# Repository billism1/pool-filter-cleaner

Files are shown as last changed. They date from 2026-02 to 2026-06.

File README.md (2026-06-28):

# Pool Filter Cleaner

A 3D-printable pool filter cleaning system designed to efficiently clean cylindrical pool filters by spraying them while they rotate. This system allows for thorough cleaning of pool filter cartridges without manual scrubbing.

**Attribution:** I designed and modeled all 3D parts for this horizontal stand myself in OpenSCAD, working from measurements I took of my own filters and equipment.

**Scope:** This is a horizontal rotisserie-style stand. The filter is carried at both ends on a single horizontal rod and spins freely on bearings while you spray it. It's an independent, personal, non-commercial project.

## Overview

This project provides a complete solution for cleaning cylindrical pool filters (typically 3 feet long × 9 inches diameter). The core system is a rotating support assembly (`filter_holder` + `leg_base` + `leg_foot`) that spins the filter during cleaning. The included nozzle model is optional and experimental.

### Key Features

- **Optional nozzle support** - Included nozzle is experimental; any strong, focused nozzle stream works
- **Rotating support system** - Allows filter to spin freely during cleaning
- **Modular aluminum rod construction** - Accommodates various filter lengths
- **Stable leg-base support design** - Provides secure support during operation
- **Standard garden hose compatibility** - 3/4" GHT threading

## Recommended Setup

This is the configuration I print and use, and the best starting point if you just want to build the stand. A complete list of every model and configuration, including all the alternative variants you can swap in, is listed and described in the sections further below: [Quick Reference](#quick-reference), [All Rendered STL Files](#all-rendered-stl-files), and [Components & Design Files](#components--design-files).

The recommended setup builds one **horizontal stand**: the filter and rod lie horizontally, supported at both ends, and the filter spins freely on bearings while you spray it.

> **Ready to print:** [`publication/pool-filter-cleaner.3mf`](publication/pool-filter-cleaner.3mf) contains all the pieces for this recommended setup, pre-arranged across multiple plates. Open it in your slicer to print them.

**Print this:**

| Qty | STL File | Purpose |
|-----|---|---|
| 4× | `leg_foot.stl` | One foot per leg (two legs on each of the two leg bases). |
| 2× | `filter_holder_interior-false_exterior-true.stl` | One pressed into each end of the cylindrical filter. |
| 1× | `leg_base_2_legs_both_sides-false.stl` | Supports one end of the horizontal aluminum rod (closed-end rod hole). |
| 1× | `leg_base_2_legs_top_insert.stl` | Supports the other end as an open-top cradle, so you can set the rod into it from above instead of pressing it into a tube end-first. |

**How it works:**
- Each **filter holder** presses into one end of the filter cartridge. An S6904ZZ bearing seats into the recessed pocket on the flange (outer) face of each holder. The pockets face *outward*, so each bearing presses up against the adjacent leg base. The single horizontal aluminum rod runs through both holders and the bearing inner races, and the rod is held fixed by the leg bases. As the filter is sprayed it spins, and the bearings carry that rotation against two stationary contacts at once: radially around the fixed rod, and axially against the fixed leg bases the bearing faces press into. Both contacts would otherwise drag, but the bearings cut the friction at each, so the filter keeps spinning freely.
- One end of the rod drops into the **top-insert cradle base**, the other end is captured by the **closed-end 2-leg base**. Using the cradle on one side lets you lay the loaded filter+rod assembly into the stand from above rather than sliding it in lengthwise.
- Each base splays into **two legs**; a **leg foot** caps each of the four leg rods for stable, non-marring contact with the ground.
- Everything is **press-fit**: bearings press into the holder pockets, and the rods press into the holder and base tubes. The set-screw holes in the tubes are optional; only add M4 screws if a joint feels too loose.

Hardware for this setup: 2× S6904ZZ bearings, 1× horizontal 3/4" rod, 4× leg rods, and optional M4 set screws. See [Additional Hardware Needed](#quick-reference) below for sizes.

The garden hose nozzle is optional; any sufficiently forceful nozzle stream works.

## Quick Reference

Pre-rendered STL files live in the [`STLs/`](STLs/) folder. They are generated from the SCAD source files with OpenSCAD (see [Generating STL Files](#generating-stl-files)).

| Component | SCAD File | STL File(s) in `STLs/` |
|---|---|---|
| **Filter Holder (Core Set, Standard)** | `filter_holder/filter_holder.scad` | `filter_holder_interior-false_exterior-true.stl` (default) |
| **Leg Base (2-leg, Core Set)** | `leg_base/leg_base_2_legs.scad` | `leg_base_2_legs_both_sides-true.stl` and `leg_base_2_legs_both_sides-false.stl` |
| **Leg Base (2-leg, Top-Insert Cradle)** | `leg_base/leg_base_2_legs_top_insert.scad` | `leg_base_2_legs_top_insert.stl` |
| **Leg Foot (Core Set)** | `leg_foot/leg_foot.scad` | `leg_foot.stl` |
| **Garden Hose Nozzle (Optional)** | `nozzle/nozzle/garden_hose_nozzle-5-prong-fan-out.scad` | `garden_hose_nozzle-5-prong-fan-out.stl` |

**Filter holder STL note:** `filter_holder.scad` exports four variants, one per combination of the `place_bearing_at_holder_interior` and `place_bearing_at_holder_exterior` flags:
- `filter_holder_interior-false_exterior-true.stl`: default (bearing seated on the exterior side)
- `filter_holder_interior-true_exterior-false.stl`
- `filter_holder_interior-true_exterior-true.stl`
- `filter_holder_interior-false_exterior-false.stl`

**Leg base STL note:** For `leg_base/leg_base_2_legs.scad`, the included exports cover both rod-hole styles:
- `*_both_sides-true.stl` (`horizontal_through_hole_both_sides = true`): rod hole goes through both sides
- `*_both_sides-false.stl` (`horizontal_through_hole_both_sides = false`): rod hole is closed on one end

**Nozzle STL note:** The garden hose nozzle is optional but is rendered like the other parts: `render_garden_hose_nozzle.ps1` (and `render_all.ps1`) export `garden_hose_nozzle-5-prong-fan-out.stl` (see [Generating STL Files](#generating-stl-files)).

**Core solution note:** `filter_holder` + `leg_base` + `leg_foot` are an atomic set and are intended to be used together. The nozzle is optional/experimental; any effective high-force nozzle stream can be used.

**Additional Hardware Needed:**
- 2× S6904ZZ ball bearings (37mm × 20mm × 9mm)
- 1× Horizontal 3/4" aluminum rod (36-40" length)
- 4× Leg support 3/4" aluminum rods (24-36" length each)
- Optional: up to 6× M4 set screws (holes are already included in the models if you want to use them)

## All Rendered STL Files

Every part is committed pre-rendered in [`STLs/`](STLs/). The [Recommended Setup](#recommended-setup) above is the specific combination I settled on and use; every other STL listed here is an available alternative, included so you can experiment with a different bearing placement, rod-hole style, or stand configuration if you want to try something else. All permutations are provided so you can pick whichever fits your build:

| STL File | Source SCAD | Parameters baked in |
|---|---|---|
| `filter_holder_interior-false_exterior-true.stl` | `filter_holder/filter_holder.scad` | bearing in flange (exterior), **default** |
| `filter_holder_interior-true_exterior-false.stl` | `filter_holder/filter_holder.scad` | bearing at plug end (interior) |
| `filter_holder_interior-true_exterior-true.stl` | `filter_holder/filter_holder.scad` | bearing pockets at both ends |
| `filter_holder_interior-false_exterior-false.stl` | `filter_holder/filter_holder.scad` | no bearing pocket |
| `leg_base_2_legs_both_sides-true.stl` | `leg_base/leg_base_2_legs.scad` | rod hole through both sides |
| `leg_base_2_legs_both_sides-false.stl` | `leg_base/leg_base_2_legs.scad` | rod hole closed on one end |
| `leg_base_2_legs_top_insert.stl` | `leg_base/leg_base_2_legs_top_insert.scad` | open-top cradle (rod laid in from above) |
| `leg_foot.stl` | `leg_foot/leg_foot.scad` | single variant |
| `garden_hose_nozzle-5-prong-fan-out.stl` | `nozzle/nozzle/garden_hose_nozzle-5-prong-fan-out.scad` | single variant, optional/experimental |

The garden hose nozzle is optional, but it is rendered alongside the other parts (`render_garden_hose_nozzle.ps1`, also covered by `render_all.ps1`). You can swap in any nozzle with an adequately forceful stream instead.

## Components & Design Files

### 1. Filter Holder

**File:** `filter_holder/filter_holder.scad`  
**STL Outputs:** four bearing-placement variants in `STLs/` (see table above); `filter_holder_interior-false_exterior-true.stl` is the default.

**Variant note:** The four STLs are the permutations of `place_bearing_at_holder_interior` and `place_bearing_at_holder_exterior`. Use the default (`interior-false_exterior-true`) unless you have a reason to seat the bearing differently.

The filter holder attaches to the pool filter cartridge and provides the mounting point for the support rod. This component includes an integrated bearing holder for smooth rotation.

**Key Features:**
- Tapered plug (76.2mm diameter) that fits snugly into the 3" filter opening
- Large flange (140mm diameter) that sits outside the filter
- Six 1-inch (25.4mm) drainage holes evenly spaced around the flange
- Bearing holder tube extension for S6904ZZ bearing (37mm OD × 20mm ID × 9mm thick)
- 4mm thick walls around bearing holder
- Ring cutout inside bearing area for clearance (starts 0.633mm from rod hole, 2.5mm thick, 2mm deep)
- 3mm diameter screw hole through bearing holder walls for securing bearing
- Central 19.05mm (3/4") hole for aluminum support rod
- All dimensions in millimeters

**Bearing Specifications:**
- S6904ZZ Ball Bearing: Stainless steel, double shielded, deep groove
- Dimensions: 37mm OD × 20mm ID × 9mm thick
- Allows filter to spin freely on the stationary aluminum rod

**Important:** Print TWO of these holders - one for each end of the filter.

### 2. Leg Base / Support Stand

**Primary file:** `leg_base/leg_base_2_legs.scad`  
**Top-insert variant:** `leg_base/leg_base_2_legs_top_insert.scad` (open-top cradle; rod is laid in from above instead of inserted end-first)  
**STL Outputs:** `STLs/leg_base_2_legs_both_sides-true.stl`, `STLs/leg_base_2_legs_both_sides-false.stl`, `STLs/leg_base_2_legs_top_insert.stl`

A leg-base connector that forms the base of the rotating support system, with two legs splaying from the horizontal rod tube.

**Specifications:**
- Designed for 3/4" (19.05mm) aluminum rods
- Horizontal tube (40mm length) for main filter rod
- Two leg tubes (47.85mm length each) angled at 45° downward
- Legs positioned 90° apart from each other
- 12° inward tilt on legs for bearing pressure toward filter
- 6mm wall thickness for structural strength
- Integrated bearing lip (2mm thick, 2mm extension) with curved flare
- Curved printing base for stable bed adhesion
- Set screw holes (4mm diameter) in all three tubes for rod retention
- Rod holes extend 35mm deep into leg tubes
- Requires BOSL2 library for advanced geometry operations

**Export variants:**
- `*_both_sides-true.stl` is rendered with `horizontal_through_hole_both_sides = true`
- `*_both_sides-false.stl` is rendered with `horizontal_through_hole_both_sides = false`

**Top-insert cradle variant:**
- `leg_base/leg_base_2_legs_top_insert.scad` is an open-top cradle: the horizontal rod is laid in from above (+Y) rather than pressed into a closed tube end-first, which can make assembly easier.

**Dependencies:**
- BOSL2 library (https://github.com/BelfrySCAD/BOSL2) - Advanced geometry and rounding functions

**Test/Development Files:**
- `leg_base/testing/base_test.scad` - Test variations of base geometry
- `leg_base/testing/curved_base.scad` - Development file for curved base design

**Important:** Print TWO of these bases - one for each end of the horizontal filter rod.

### 3. Leg Foot

**File:** `leg_foot/leg_foot.scad`  
**STL Output:** `STLs/leg_foot.stl`

Leg feet pair with the leg-base tubes and are part of the core support set.

**Important:** Print TWO leg feet and use them with the matching holder/base set.

### 4. Garden Hose Nozzle (Optional / Experimental)

#### Main Design File
**File:** `nozzle/nozzle/garden_hose_nozzle-5-prong-fan-out.scad`  
**STL Output:** `STLs/garden_hose_nozzle-5-prong-fan-out.stl` (rendered by `render_garden_hose_nozzle.ps1`)

This nozzle design is optional and experimental. You can use any nozzle that provides an adequately forceful stream for cleaning.

**Recommended print/process for watertightness:**
- Print the nozzle in ABS or ASA (recommended)
- Acetone vapor smooth both the inside and outside surfaces after printing
- This helps eliminate layer-line seepage; in ASA testing, small water beads/leaks through print lines stopped after vapor smoothing

**Specifications:**
- 3/4" female garden hose threading (GHT)
- 5 outlet nozzles with 1.72mm diameter openings
- Total outlet area: 11.69 mm²
- Hex grip ring for easy tightening (toggleable)
- Smooth hydrodynamic internal transitions for optimal water distribution
- Multi-stage hull transitions from cylinder to individual cone nozzles

**Dependencies:**
- `nozzle/nozzle/Threading.scad` - Library for generating 3/4" GHT female threads
- `nozzle/nozzle/Naca_sweep.scad` - Sweep and extrusion library for complex geometry

### Library Files

#### Threading.scad
**File:** `nozzle/nozzle/Threading.scad`

Comprehensive threading library by Rudolf Huttary (Berlin, 2016-2021) for generating various thread types in OpenSCAD.

**Capabilities:**
- Standard metric threads (ISO)
- ACME threads
- Multiple helix threads
- Left-hand and right-hand threads
- Customizable pitch, diameter, windings, and thread angle
- Used for generating 3/4" GHT (Garden Hose Thread) in nozzle designs

**Key Functions:**
- `threading()` - Creates a threaded rod or bolt
- `Threading()` - Creates a threaded nut or female thread

#### Naca_sweep.scad
**File:** `nozzle/nozzle/Naca_sweep.scad`

Sweep and extrusion library by Rudolf Huttary (2015-2020) for creating complex 3D shapes from 2D profiles.

**Capabilities:**
- Sweep 2D profiles along 3D paths
- Create smooth transitions between different cross-sections
- Skin multiple polygons together
- Matrix/vector transformations (translation, rotation, scaling)
- Path subdivision for smooth curves

**Key Functions:**
- `sweep()` - Main sweep/extrusion function
- `sweep_path()` - Sweep a shape along a path
- Affine transformations: `T()`, `R()`, `S()` for translate, rotate, scale

## Assembly Overview

The complete cleaning system consists of:

### Hardware Requirements
1. **Two 3D-printed filter holders** (`filter_holder/filter_holder.scad`)
   - Install one on each end of the filter cartridge
   
2. **Two 3D-printed leg bases** (`leg_base/leg_base_2_legs.scad`)
   - Position one at each end of the horizontal support rod

3. **Two 3D-printed leg feet** (`leg_foot/leg_foot.scad`)
   - Install on the ends of the inserted leg rods
   
4. **Optional 3D-printed garden hose nozzle** (`nozzle/nozzle/garden_hose_nozzle-5-prong-fan-out.scad`)
   - Optional experimental nozzle; any nozzle with an adequately forceful stream works
   
5. **Two S6904ZZ stainless steel ball bearings**
   - 37mm OD × 20mm ID × 9mm thick
   - One for each filter holder
   
6. **One horizontal 3/4" (19.05mm) aluminum rod**
   - Length varies based on filter size (typically 36-40" for standard filters)
   - Passes through bearing holders and leg bases
   
7. **Four 3/4" (19.05mm) aluminum rod legs**
   - Two legs per base (four total for both ends)
   - Length depends on desired working height (typically 24-36")
   
8. **Optional set screws** (M4 or #8-32)
   - Holes are already included in the printed models if you want to secure rods in filter holders and leg bases
   - Up to six screws total (one per tube connection)

### Assembly Steps

1. **Prepare filter holders:**
   - Press S6904ZZ bearings into the bearing holder tubes on each filter holder
   - Secure bearings with 3mm screws through side holes
   
2. **Mount filter holders to filter:**
   - Insert tapered plugs into both ends of the pool filter cartridge
   - The flanges should sit flat against the filter ends
   - Water drainage occurs through the six holes in each flange
   
3. **Install horizontal rod:**
   - Slide the horizontal 3/4" aluminum rod through both filter holders
   - The rod passes through the bearings, allowing the filter to rotate freely
   - Adjust rod position to center the filter
   
4. **Attach leg bases:**
   - Slide one leg base onto each end of the horizontal rod
   - Position them outside the filter holders
   - Optional: tighten set screws in the horizontal tubes to secure bases
   
5. **Install support legs:**
   - Insert two 3/4" aluminum rods into the angled leg sockets on each base
   - Adjust leg extension for desired working height
   - Optional: tighten set screws to secure legs
   
6. **Connect nozzle (optional):**
   - Attach the included 5-prong nozzle or any suitable high-force nozzle to your garden hose
   - Hand-tighten using the hex grip ring (if using the included model)
   
7. **Operation:**
   - Position the assembly on level ground
   - Turn on water supply
   - Manually rotate the filter or let water pressure cause rotation
   - The five concentrated jets clean the filter pleats thoroughly

The bearings allow the filter to spin freely on the stationary aluminum rod while water jets from the nozzle clean the exterior.

## 3D Printing Instructions

### General Settings
- **Material:** PETG or ABS recommended for outdoor durability and chemical resistance
  - PETG: Easier to print, good UV resistance, excellent layer adhesion
  - ABS: Higher temperature resistance, more rigid, requires heated enclosure
- **Infill:** 30-40% for structural components (leg bases, filter holders), 20-30% for nozzle
- **Layer Height:** 0.2mm standard, 0.15mm for higher detail
- **Print Speed:** 40-60mm/s for best quality
- **Supports:** Minimal - most designs optimized for support-free printing

### Component-Specific Notes

#### Filter Holder
- **Orientation:** Print with flange side down (largest flat surface on build plate)
- **Supports:** None required - bearing holder and drain holes designed to print without supports
- **Post-Processing:** Clean any stringing from drain holes and bearing holder

#### Leg Base
- **Orientation:** Print with curved base on build plate (already optimized for this orientation)
- **Supports:** None required - design includes integrated printing base that gets cut off
- **Post-Processing:** May need to drill set screw holes to final size depending on printer precision

#### Garden Hose Nozzle
- **Orientation:** Print with threaded end down (flat surface on build plate)
- **Supports:** Minimal supports may be needed for underside of hex grip ring
- **Thread Quality:** Ensure $fn is set to 180 or higher for smooth threads
- **Material Recommendation:** ABS or ASA for best water sealing performance
- **Post-Processing:** Use acetone vapor smoothing on both inside and outside surfaces to reduce/close layer-line seepage, then test thread fit with garden hose

### Quality Tips
1. **First Layer:** Critical for all parts - ensure proper bed leveling and adhesion
2. **Thread Testing:** Print a small thread test piece before committing to full nozzle print
3. **Bearing Fit:** Filter holder bearing pocket should be snug - may need light sanding for perfect fit
4. **Rod Holes:** Should allow smooth sliding of 3/4" aluminum rod - sand lightly if too tight
5. **Layer Adhesion:** Important for water-tight performance of nozzle - avoid drafts and temperature fluctuations

## Usage & Operation

### Setup
1. **Assemble the base structure** with aluminum rods and 3D-printed leg bases
2. **Install bearings** into filter holders and secure with set screws
3. **Mount filter holders** on both ends of the pool filter cartridge
4. **Slide horizontal rod** through filter holders and bearings
5. **Attach leg bases** to rod ends (optional set screws can be used via the built-in holes)
6. **Insert support legs** into angled sockets (optional set screws can be used via the built-in holes)
7. **Level the assembly** on flat ground, adjust leg heights if needed

### Cleaning Operation
1. **Connect nozzle** (included optional model or any suitable high-force nozzle) to garden hose with good water pressure (30-50 PSI recommended)
2. **Position nozzle** 6-12 inches from filter surface
3. **Turn on water** - the five jets will spray concentrated streams across the filter
4. **Rotate the filter** manually or allow water pressure to spin it on the bearings
5. **Move nozzle** along the length of the filter for complete coverage
6. **Continue until clean** - typically 2-5 minutes per filter depending on debris level

### Maintenance
- **After each use:** Rinse nozzle to prevent buildup
- **Weekly (if using set screws):** Check set screws and tighten if needed
- **Monthly:** Inspect bearings for smooth rotation, clean if necessary
- **Annually:** Check 3D-printed parts for wear or UV damage

### Safety Notes
- Always use on level ground to prevent tipping
- If using set screws, ensure they are tight before adding water pressure
- Do not exceed 80 PSI water pressure to avoid damaging components
- Keep electrical equipment away from water spray area

## Design Software & Dependencies

### OpenSCAD
All components are designed in **OpenSCAD** (parametric 3D CAD modeler), allowing for easy customization and adjustments for different filter sizes or rod diameters.

**Download:** https://openscad.org/

**Recommended Version:** OpenSCAD 2021.01 or newer

### Required Libraries

#### BOSL2 (for leg base SCAD files)
**Repository:** https://github.com/BelfrySCAD/BOSL2  
**Purpose:** Advanced geometric operations, rounding, and shape manipulation  
**Installation:** 
1. Download or clone the BOSL2 repository
2. Place in OpenSCAD's library path or in the project directory
3. The leg base files use `include <BOSL2/std.scad>`

#### Threading.scad (included)
**Location:** `nozzle/nozzle/Threading.scad`  
**Purpose:** Generate GHT and other thread types  
**Author:** Rudolf Huttary, Berlin (2016-2021)  
**Note:** Already included in project, no separate installation needed

#### Naca_sweep.scad (included)
**Location:** `nozzle/nozzle/Naca_sweep.scad`  
**Purpose:** Sweep and extrusion operations for complex geometry  
**Author:** Rudolf Huttary, Berlin (2015-2020)  
**Note:** Already included in project, no separate installation needed

### Rendering Settings

For quick previews during development:
```openscad
$fn = 60;  // Lower resolution, faster rendering
```

For final STL export:
```openscad
$fn = 180;  // Higher resolution, smoother curves
```

Each file has its `$fn` parameter clearly marked at the top for easy adjustment.

## Generating STL Files

Pre-rendered STLs are committed in [`STLs/`](STLs/), so you only need to regenerate them if you change a SCAD file or want a different parameter variant. All generation goes through OpenSCAD; the PowerShell scripts are just a convenience wrapper around it.

**Prerequisites:**
- [OpenSCAD](https://openscad.org/) installed (2021.01 or newer; a recent Nightly build is recommended because it ships the more robust `manifold` geometry backend).
- The [BOSL2](https://github.com/BelfrySCAD/BOSL2) library on OpenSCAD's library path, required by all `leg_base` SCAD files. The nozzle's `Threading.scad` and `Naca_sweep.scad` are already bundled in the repo.

### Option A: PowerShell scripts (Windows)

The repo includes `render_*.ps1` scripts that drive OpenSCAD for you. Each part has its own script, and `render_all.ps1` runs every one of them. They write into the `STLs/` folder and automatically:
- locate OpenSCAD (preferring `C:\Program Files\OpenSCAD (Nightly)\openscad.exe`, then the stable install, then `openscad` on `PATH`),
- enable `--backend=manifold` when the installed build supports it,
- render every parameter permutation for the multi-variant parts.

```powershell
# Render everything into STLs\
powershell -ExecutionPolicy Bypass -File render_all.ps1

# Or render a single part
powershell -ExecutionPolicy Bypass -File render_filter_holder.ps1
powershell -ExecutionPolicy Bypass -File render_leg_base_2_legs.ps1
powershell -ExecutionPolicy Bypass -File render_leg_base_2_legs_top_insert.ps1
powershell -ExecutionPolicy Bypass -File render_leg_foot.ps1
powershell -ExecutionPolicy Bypass -File render_garden_hose_nozzle.ps1
```

| Script | Renders |
|---|---|
| `render_all.ps1` | Every part script below |
| `render_filter_holder.ps1` | 4 filter-holder bearing-placement variants |
| `render_leg_base_2_legs.ps1` | 2-leg base, both `horizontal_through_hole_both_sides` values |
| `render_leg_base_2_legs_top_insert.ps1` | Top-insert cradle base (single variant) |
| `render_leg_foot.ps1` | Leg foot (single variant) |
| `render_garden_hose_nozzle.ps1` | Garden hose nozzle (single variant, optional) |

`render_common.ps1` holds the shared OpenSCAD-locating and rendering helpers; it is dot-sourced by the others and is not run directly.

### Option B: OpenSCAD directly

Open any `.scad` file in the OpenSCAD GUI and use **File → Export → Export as STL** (after a full render with F6), or render from the command line. The command line is what the PowerShell scripts call under the hood, so you can reproduce any committed STL exactly.

```bash
# Single-variant parts
openscad --backend=manifold -o STLs/leg_foot.stl leg_foot/leg_foot.scad
openscad --backend=manifold -o STLs/leg_base_2_legs_top_insert.stl leg_base/leg_base_2_legs_top_insert.scad

# Parameterized variants: override values with -D
openscad --backend=manifold \
  -D place_bearing_at_holder_interior=false \
  -D place_bearing_at_holder_exterior=true \
  -o STLs/filter_holder_interior-false_exterior-true.stl \
  filter_holder/filter_holder.scad

openscad --backend=manifold \
  -D horizontal_through_hole_both_sides=true \
  -o STLs/leg_base_2_legs_both_sides-true.stl \
  leg_base/leg_base_2_legs.scad

# Optional nozzle (also produced by render_garden_hose_nozzle.ps1)
openscad --backend=manifold \
  -o STLs/garden_hose_nozzle-5-prong-fan-out.stl \
  nozzle/nozzle/garden_hose_nozzle-5-prong-fan-out.scad
```

Notes:
- Drop `--backend=manifold` on older OpenSCAD builds that don't support it.
- Each SCAD file's `$fn` defaults to 180 for smooth final exports; lower it to ~60 for faster preview renders (the nozzle threads in particular want `$fn` 180+).

## Project Status

### Completed Components ✅
- **Garden hose nozzle** - Optional experimental add-on
  - 5-prong fan-out configuration optimized for filter cleaning
  - GHT threading with hex grip for easy installation
   - Any adequately forceful nozzle stream can be used instead
  
- **Filter holder** - Complete design with bearing integration
  - Tapered plug fits standard 3" pool filter openings
  - Integrated S6904ZZ bearing holder with retention screw
  - Drainage holes for water flow
  - Ring cutout for proper bearing clearance
  
- **Leg base / Support stand** - Fully designed and ready for printing
   - 2-leg connector with top-insert cradle variant available
  - Curved printing base for stability
  - Bearing lip for smooth rotation interface
  - Set screw holes for secure rod retention

### Documentation 📋
- ✅ Component specifications documented
- ✅ File organization and purposes documented
- ✅ Assembly instructions provided
- ✅ Hardware requirements listed
- ✅ Printing parameters specified
- 🚧 Photos/renders of assembled system - Pending
- 🚧 Video demonstration - Pending

### Future Enhancements 💡
- Extended reach nozzle variants for larger filters
- Motorized rotation option
- Alternative bearing holder designs for different bearing sizes
- Adjustable height leg bases
- Integrated tool holder for maintenance accessories

## License

This project is licensed under the MIT License. See [LICENSE](LICENSE) for details.

Feel free to modify and improve the designs for your own use.

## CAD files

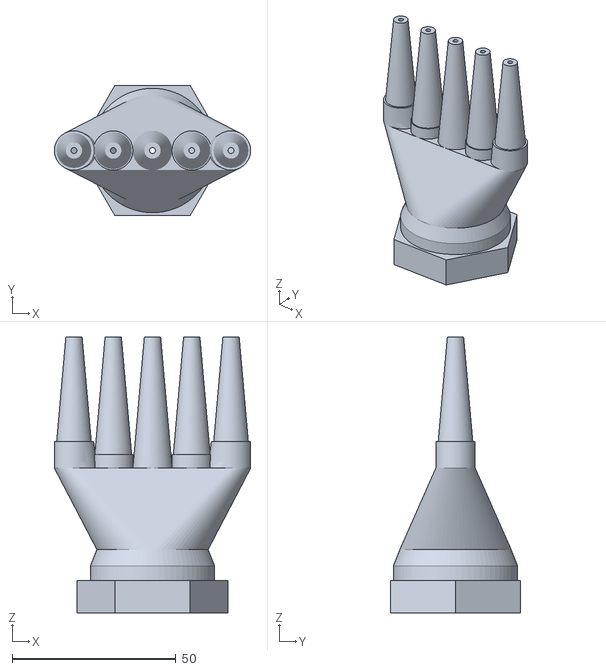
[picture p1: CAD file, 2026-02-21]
nozzle/testing/nozzle2/STLs/garden_hose_nozzle-5-prong-fan-out-2 - rev2.stl
60.0 x 39.8 x 84.4

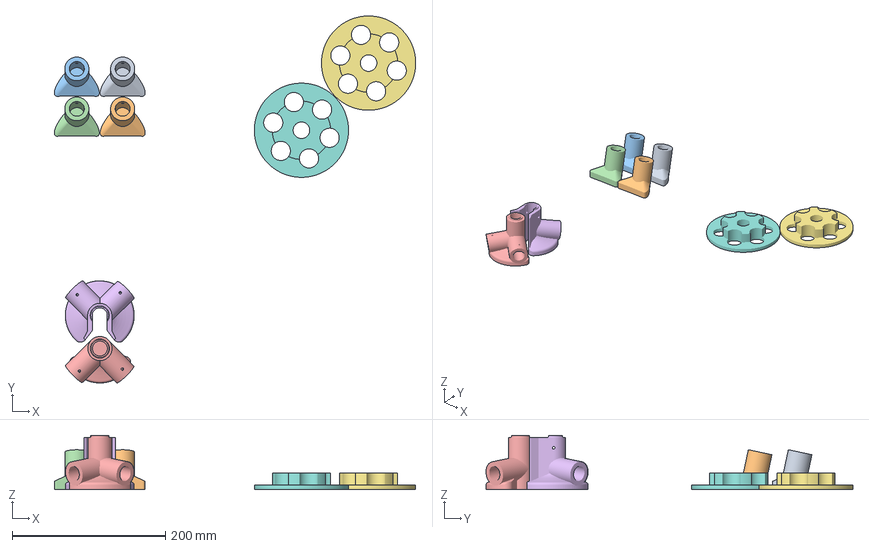
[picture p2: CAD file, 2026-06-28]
publication/pool-filter-cleaner.3mf
471.8 x 479.2 x 71.0 mm
leg_foot.stl x 4
leg_base_2_legs_both_sides-false.stl
leg_base_2_legs_top_insert.stl
filter_holder_interior-false_exterior-true.stl x 2

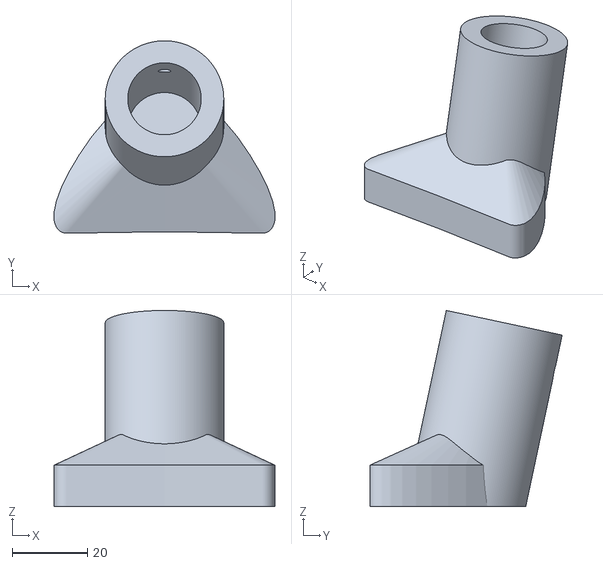
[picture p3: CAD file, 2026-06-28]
STLs/leg_foot.stl
58.8 x 51.2 x 52.2

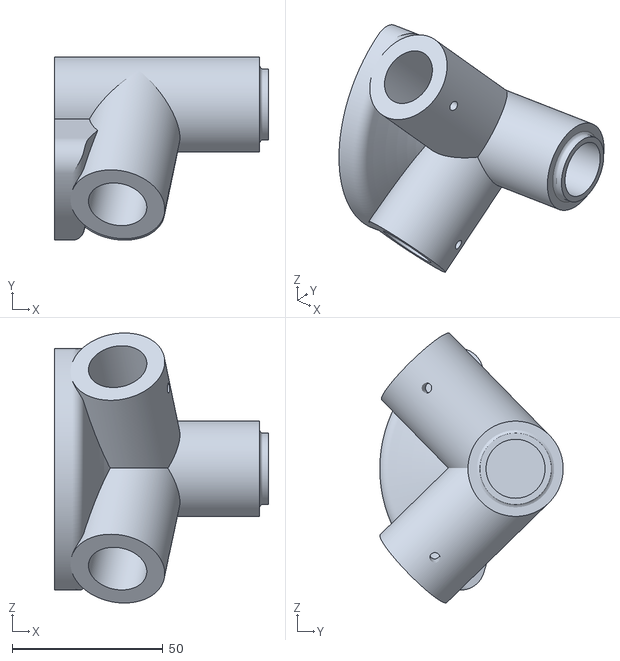
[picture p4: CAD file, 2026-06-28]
STLs/leg_base_2_legs_both_sides-false.stl
71.0 x 60.8 x 89.5

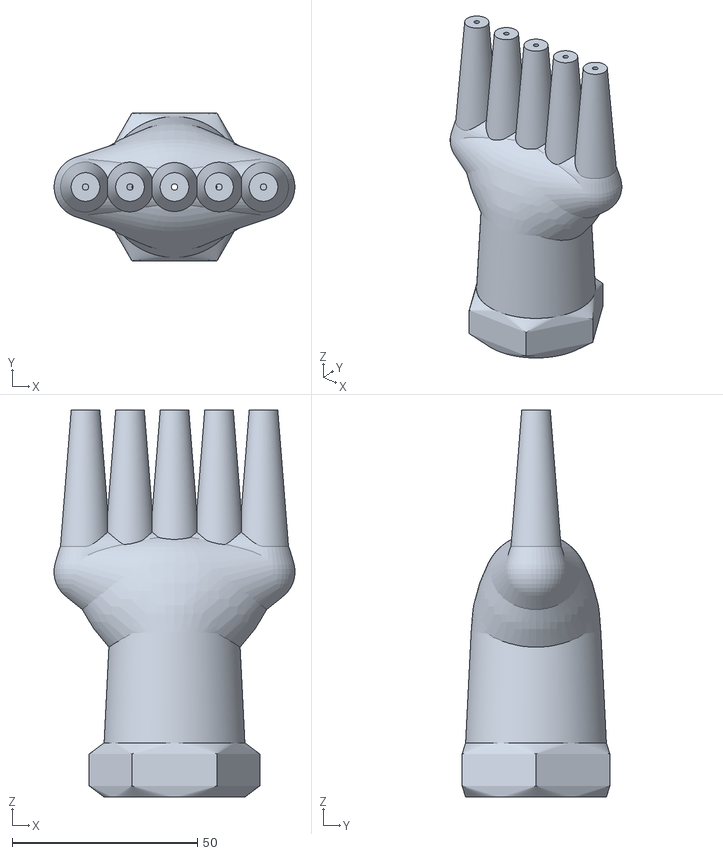
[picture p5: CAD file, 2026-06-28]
STLs/garden_hose_nozzle-5-prong-fan-out.stl
64.9 x 39.8 x 104.4

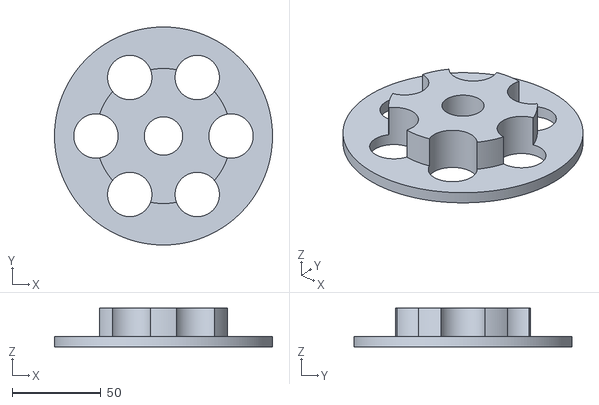
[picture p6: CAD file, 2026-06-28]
STLs/filter_holder_interior-false_exterior-true.stl
123.0 x 123.0 x 22.0

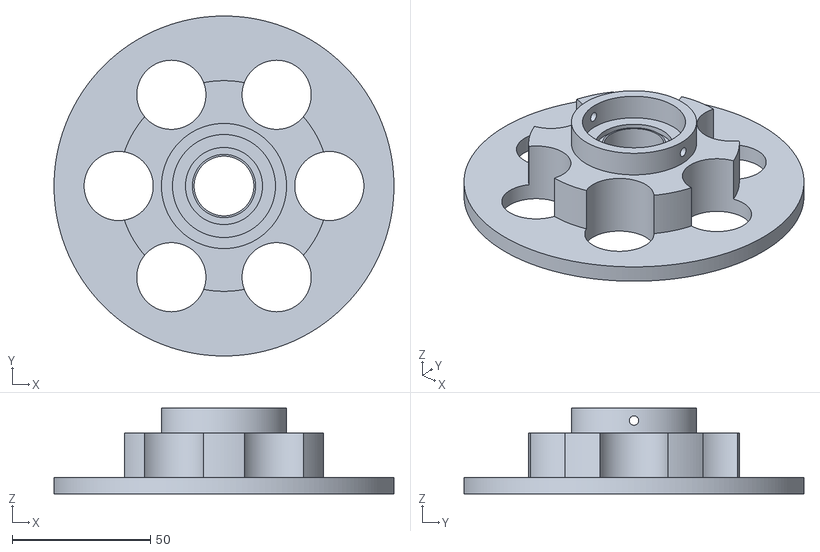
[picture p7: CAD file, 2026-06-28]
STLs/filter_holder_interior-true_exterior-false.stl
123.0 x 123.0 x 31.0

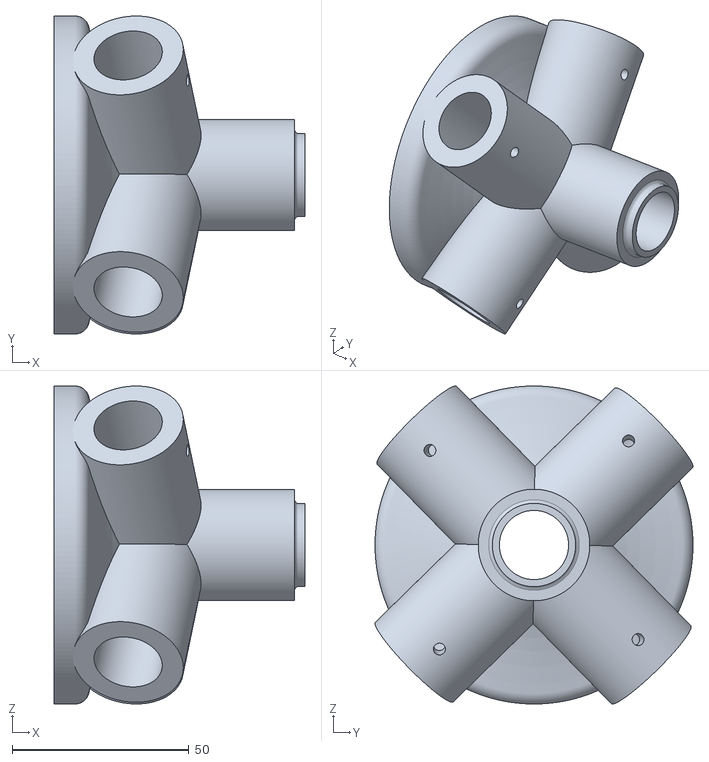
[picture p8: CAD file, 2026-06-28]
STLs/leg_base_4_legs_both_sides-true.stl
71.0 x 90.0 x 90.0

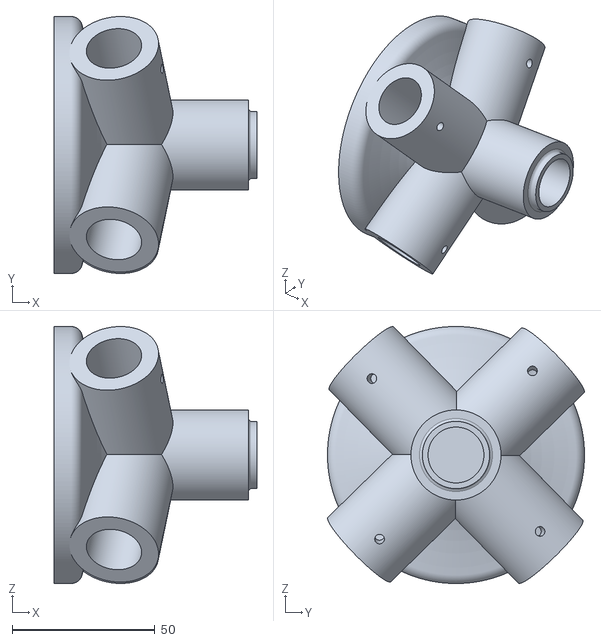
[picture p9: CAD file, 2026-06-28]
STLs/leg_base_4_legs_both_sides-false.stl
71.0 x 90.0 x 90.0

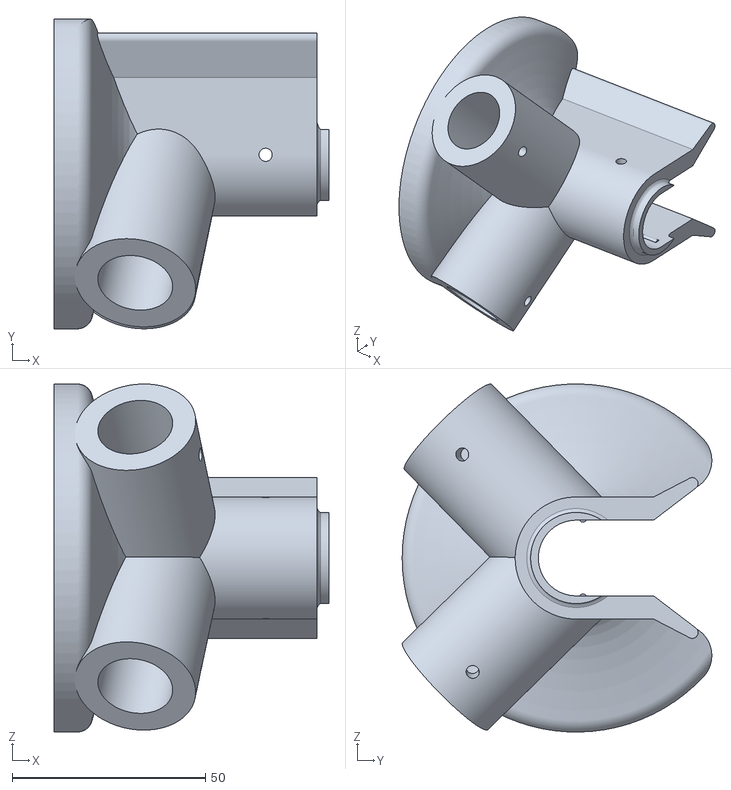
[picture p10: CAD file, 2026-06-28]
STLs/leg_base_2_legs_top_insert.stl
71.0 x 80.1 x 90.0

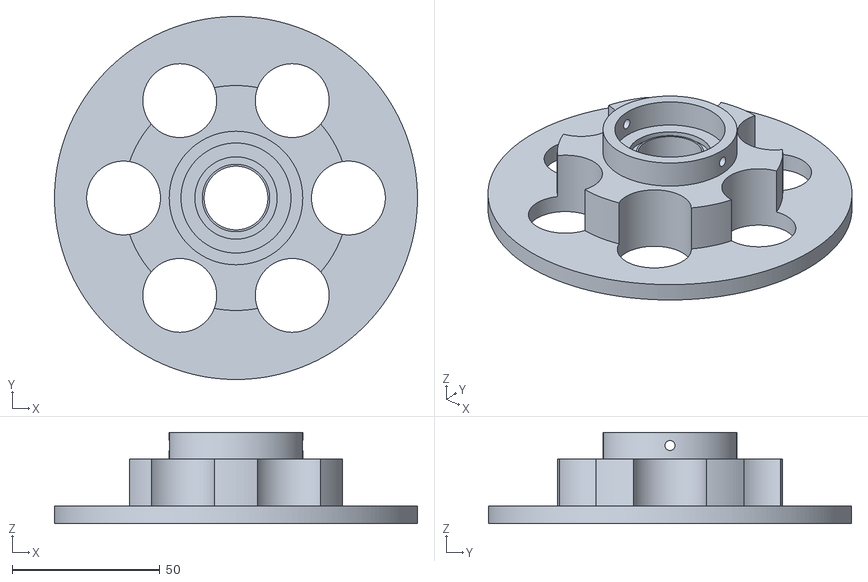
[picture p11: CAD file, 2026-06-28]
STLs/filter_holder_interior-true_exterior-true.stl
123.0 x 123.0 x 31.0

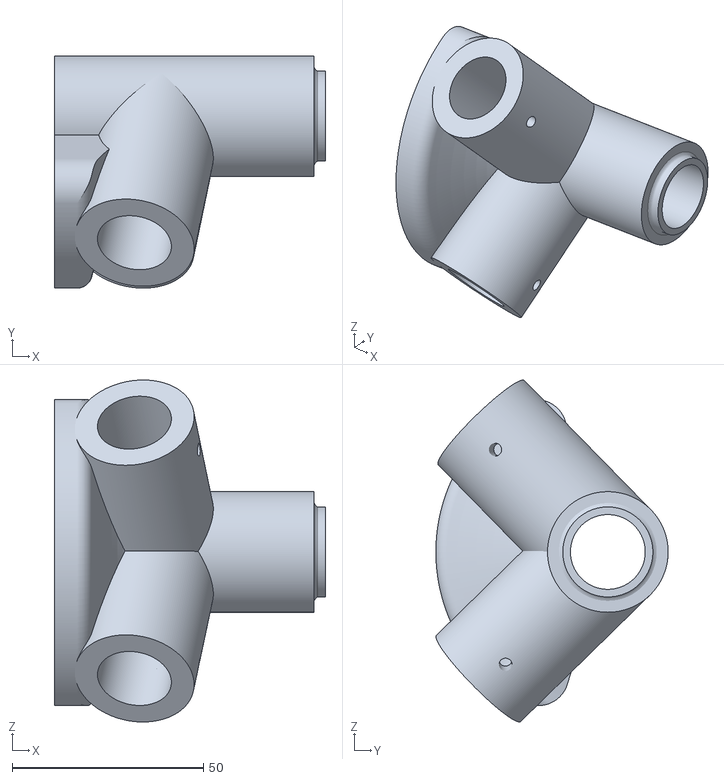
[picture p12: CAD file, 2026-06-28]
STLs/leg_base_2_legs_both_sides-true.stl
71.0 x 60.8 x 89.5

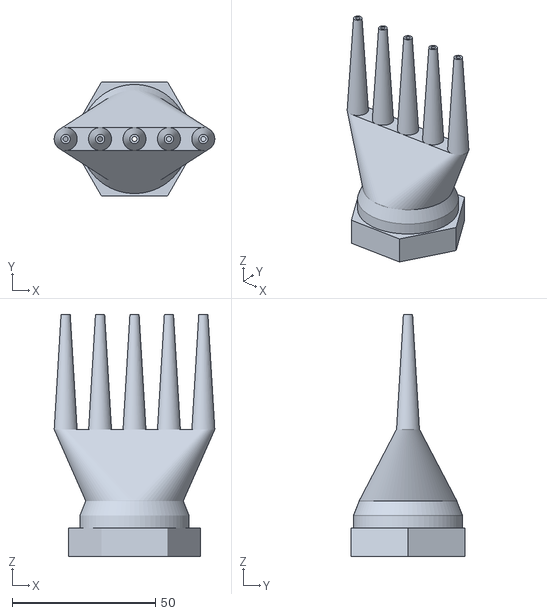
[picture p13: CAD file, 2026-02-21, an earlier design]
nozzle/testing/nozzle2/STLs/garden_hose_nozzle-5-prong-fan-out-2 - rev1.stl
56.0 x 39.8 x 84.4

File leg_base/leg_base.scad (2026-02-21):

// Pool Filter Cleaner - Base Holder
// Holds 3/4" aluminum rod horizontally (for filter cylinder)
// Plus two 3/4" aluminum rod legs angled down at 45 degrees, 90 degrees apart
// Creates a stable tripod support structure (use 2 of these bases, one at each end)

include <BOSL2/std.scad>
// https://github.com/BelfrySCAD/BOSL2

$fn = 180;  // Reduce to 60 for faster preview, increase to 180+ to for final render

// Rod specifications
rod_diameter = 19.05;        // 3/4" aluminum rod = 19.05mm
rod_clearance = 0.5;         // Clearance for easy insertion
rod_hole_diameter = rod_diameter + rod_clearance;

// Tube dimensions
tube_wall_thickness = 6;     // Thick walls for strength
tube_inner_diameter = rod_hole_diameter;
tube_outer_diameter = tube_inner_diameter + (tube_wall_thickness * 2);

// Length dimensions
horizontal_tube_length = 40;  // Length of horizontal tube section
leg_tube_length = 47.85;         // Length of each leg tube section
leg_hole_depth = 35;          // How deep leg holes go (stops well before center)

// Leg angle
leg_angle = 45;  // Degrees down from horizontal
inward_tilt_angle = 12;  // Slight inward tilt toward filter for bearing pressure

// Bearing lip dimensions
bearing_lip_extension = 2;   // How far the lip extends inward (mm)
bearing_lip_thickness = 2;   // Thickness of the bearing lip wall (mm)
bearing_lip_od = tube_inner_diameter + (bearing_lip_thickness * 2);  // Outer diameter matches tube inner diameter
bearing_lip_id = bearing_lip_od - (bearing_lip_thickness * 2);  // Inner diameter for rod clearance
bearing_lip_flare_length = 1; // Length of the curved flare section
bearing_lip_flare_amount = 1; // How much it flares outward (mm added to radius)

// Horizontal hole configuration
horizontal_through_hole_both_sides = true;  // If true, rod hole goes through both sides; if false, only extends in positive X direction

// Printing base configuration
printing_base_cutoff = -18;     // Where to cut (negative X) - adjusts how much is flat
printing_base_offset = -10;     // Additional offset to move curved base left/right (negative = left)

// Curved printing base dimensions
printing_base_radius = 45;      // Radius of the bottom of curved base
printing_base_neck_radius = (tube_outer_diameter / 2); // Radius of neck - matches horizontal tube
printing_base_height = 9;      // Height of the flat base part
printing_base_taper_height = 15; // Vertical distance of the concave curve
printing_base_neck_height = 6;  // Height of the straight top section
printing_base_round_radius = 4; // Radius for rounding edges of curved base
printing_base_total_height = printing_base_height + printing_base_taper_height + printing_base_neck_height; // Total height of the curved base

// Set screw dimensions
set_screw_diameter = 3.4;                                // Diameter of set screw holes. 3.4mm (85% of 4mm) for M4 screws, which are common and provide good holding strength.
set_screw_depth = tube_outer_diameter / 2 + 2;           // Depth of screw hole (goes halfway through + a bit)
set_screw_position = leg_tube_length - 10;               // Distance from leg origin (near the open end)
horizontal_screw_position = horizontal_tube_length - 10; // Position for horizontal tube screw (far from legs)

module rod_tube(length) {
    // Simple tube to hold aluminum rod - extends in positive Z direction only
    difference() {
        cylinder(d = tube_outer_diameter, h = length, center = false);
        cylinder(d = tube_inner_diameter, h = length + 1, center = false);
    }
}

// Central hub removed - using curved base instead

module curved_bearing_lip() {
    // Bearing lip with curved flare at the base
    // Curves at pipe connection, flat ring at bearing contact surface
    
    lip_r = bearing_lip_od / 2;         // Radius of the bearing contact surface
    max_flare_r = tube_outer_diameter / 2 - 0.5; // Maximum flare (just under pipe outer)
    
    // Define the 2D profile path
    profile_path = [
        [0, 0],  // Center at pipe connection
        [lip_r + bearing_lip_flare_amount, 0],  // Start with flared radius at pipe
        
        // Curved flare section - contracts inward as it extends out
        for (t = [0.1 : 0.1 : 0.9]) 
            let(
                z = t * bearing_lip_flare_length,
                // Concave curve inward - stays wider longer then contracts
                r = lip_r + bearing_lip_flare_amount * pow(1-t, 2)
            ) [r, z],
        
        [lip_r, bearing_lip_flare_length],  // End of flare at normal lip radius
        [lip_r, bearing_lip_flare_length + bearing_lip_extension],  // Straight section (flat ring for bearing)
        [0, bearing_lip_flare_length + bearing_lip_extension]  // Back to center at bearing contact
    ];
    
    // Create the 3D shape
    rotate_sweep(profile_path, angle=360);
}

module curved_printing_base() {
    // Curved base geometry from curved-base.scad
    // Uses parameters defined at top of file
    
    // Define the 2D profile path - includes center points for solid top/bottom
    profile_path = [
        [0, 0],                              // Center bottom (must be x=0)
        [printing_base_radius, 0],           // Bottom outer edge
        [printing_base_radius, printing_base_height], // Top edge of base
        
        // Concave Transition (The Scoop)
        for (t = [0.1 : 0.1 : 0.9]) 
            let(
                z = printing_base_height + t * printing_base_taper_height,
                r = printing_base_neck_radius + (printing_base_radius - printing_base_neck_radius) * pow(1-t, 2)
            ) [r, z],
            
        [printing_base_neck_radius, printing_base_height + printing_base_taper_height], // Start of straight neck
        [printing_base_neck_radius, printing_base_height + printing_base_taper_height + printing_base_neck_height], // Top outer edge
        [0, printing_base_height + printing_base_taper_height + printing_base_neck_height] // Center top (must be x=0)
    ];
    
    // Round the corners and spin it
    // Set radius=0 at center points (top and bottom) to remove dimples
    // Set radius=0 at bottom outer edge for sharp corner
    // Set radius=0 at top outer edge for sharp 90-degree corner
    // Path has 15 points: [0]=center bottom, [1]=bottom outer, [2-12]=profile, [13]=top outer, [14]=center top
    radii = [for (i = [0:14]) 
        (i == 0 || i == 1 || i == 13 || i == 14) ? 0 : printing_base_round_radius]; // Sharp corners at bottom and top
    
    rounded_profile = round_corners(profile_path, radius=radii);
    rotate_sweep(rounded_profile, angle=360);
}

module filter_base() {
    difference() {
        union() {
            // Horizontal tube for main filter rod (extends in positive X direction only)
            rotate([0, 90, 0])
                rod_tube(horizontal_tube_length);
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

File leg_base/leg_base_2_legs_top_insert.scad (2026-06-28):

// Pool Filter Cleaner - Base Holder (Top-Insert Cradle Variant)
// Open-top cradle holds 3/4" aluminum rod horizontally (for filter cylinder)
// Rod is laid in from above (+Y direction) rather than inserted end-first
// Plus two 3/4" aluminum rod legs angled down at 45 degrees, 90 degrees apart
// Creates a stable tripod support structure (use 2 of these bases, one at each end)

include <BOSL2/std.scad>
// https://github.com/BelfrySCAD/BOSL2

$fn = 180;  // Reduce to 60 for faster preview, increase to 180+ to for final render

printing_base_trim_enabled = true; // If true, use partial sweep to save material; if false, keep base fully round

// Rod specifications
rod_diameter = 19.05;        // 3/4" aluminum rod = 19.05mm
rod_clearance = 0.5;         // Clearance for easy insertion
rod_hole_diameter = rod_diameter + rod_clearance;

// Tube dimensions
tube_wall_thickness = 6;     // Thick walls for strength
tube_inner_diameter = rod_hole_diameter;
tube_outer_diameter = tube_inner_diameter + (tube_wall_thickness * 2);

// Length dimensions
horizontal_tube_length = 40;  // Length of horizontal cradle section
leg_tube_length = 47.85;         // Length of each leg tube section
leg_hole_depth = 35;          // How deep leg holes go (stops well before center)
cradle_wall_extension = 30;   // Height of cradle walls above tube centerline (mm) for top-insert rod loading
cradle_flare_height = 10;     // Height of the flared/rounded section at the top of cradle walls (mm)
cradle_flare_amount = 5;      // How far each wall flares outward at the top (mm)
cradle_snap_protrusion = 1;   // How far snap-fit ridges protrude inward from each wall (mm) to retain the rod

// Leg angle
leg_angle = 45;  // Degrees down from horizontal
inward_tilt_angle = 12;  // Slight inward tilt toward filter for bearing pressure

// Bearing lip dimensions
bearing_lip_extension = 2;   // How far the lip extends inward (mm)
bearing_lip_thickness = 2;   // Thickness of the bearing lip wall (mm)
bearing_lip_od = tube_inner_diameter + (bearing_lip_thickness * 2);  // Outer diameter matches tube inner diameter
bearing_lip_id = bearing_lip_od - (bearing_lip_thickness * 2);  // Inner diameter for rod clearance
bearing_lip_flare_length = 1; // Length of the curved flare section
bearing_lip_flare_amount = 1; // How much it flares outward (mm added to radius)

// Printing base configuration
printing_base_cutoff = -18;     // Where to cut (negative X) - adjusts how much is flat
printing_base_offset = -10;     // Additional offset to move curved base left/right (negative = left)

// Curved printing base dimensions
printing_base_radius = 45;      // Radius of the bottom of curved base
printing_base_neck_radius = (tube_outer_diameter / 2); // Radius of neck - matches horizontal tube
printing_base_height = 9;      // Height of the flat base part
printing_base_taper_height = 15; // Vertical distance of the concave curve
printing_base_neck_height = 6;  // Height of the straight top section
printing_base_round_radius = 4; // Radius for rounding edges of curved base
printing_base_sweep_angle = 299; // Arc from left cradle wall, through bottom (-Y), to right cradle wall
printing_base_sweep_rotation = 120.5; // Rotational start angle so arc avoids the cradle opening (+Y side)
printing_base_end_round_radius = 8; // Radius for rounding the angular ends of the partial sweep (set to 0 to disable; uses minkowski)
printing_base_total_height = printing_base_height + printing_base_taper_height + printing_base_neck_height; // Total height of the curved base

// Set screw dimensions
set_screw_diameter = 3.4;                                // Diameter of set screw holes. 3.4mm (85% of 4mm) for M4 screws, which are common and provide good holding strength.
set_screw_depth = tube_outer_diameter / 2 + 2;           // Depth of screw hole (goes halfway through + a bit)
set_screw_position = leg_tube_length - 10;               // Distance from leg origin (near the open end)
cradle_set_screw_enabled = true;                             // Whether to include cradle set screw holes
cradle_set_screw_position = horizontal_tube_length / 1.5;  // X position of cradle set screws (2/3 along cradle length)

module rod_tube(length) {
    // Simple tube to hold aluminum rod - extends in positive Z direction only
    difference() {
        cylinder(d = tube_outer_diameter, h = length, center = false);
        cylinder(d = tube_inner_diameter, h = length + 1, center = false);
    }
}

module rod_cradle(length) {
    // Open-top cradle for aluminum rod - U-shaped cross-section
    // Bottom semicircle holds the rod, walls extend upward for top-insert loading
    // Walls have rounded flared tops to guide the rod into the cradle
    // Oriented along +Z axis (same as rod_tube), to be rotated into place
    
    // Straight wall section (without flare height)
    straight_height = cradle_wall_extension - cradle_flare_height;
    
    // Main cradle body with straight walls
    linear_extrude(height = length) {
        difference() {
            union() {
                // Bottom semicircle (outer wall) - Y <= 0 half
                intersection() {
                    circle(d = tube_outer_diameter);
                    translate([0, -tube_outer_diameter / 2])
                        square([tube_outer_diameter, tube_outer_diameter], center = true);
                }
                // Left wall extending upward (straight portion)
                translate([-(tube_outer_diameter / 2), 0])
                    square([tube_wall_thickness, straight_height]);
                // Right wall extending upward (straight portion)
                translate([(tube_inner_diameter / 2), 0])
                    square([tube_wall_thickness, straight_height]);
            }
            // Inner bore - bottom semicircle only
            intersection() {
                circle(d = tube_inner_diameter);
                translate([0, -tube_outer_diameter / 2])
                    square([tube_outer_diameter, tube_outer_diameter], center = true);
            }
        }
    }    
    
    // Flared tops with rounded edges
    // Hull between bottom rectangle (wall width) and outer cylinder (rounded tip)
    // Flares outward only — inner face stays straight, outer face widens
    
    flare_top_r = tube_wall_thickness / 4;  // Small radius for smooth tapered tip
    
    // Left wall flare (flares outward in -X direction)
    hull() {
        // Bottom of flare: matches straight wall
        translate([-(tube_outer_diameter / 2), straight_height, 0])
            cube([tube_wall_thickness, 0.01, length]);
        // Top of flare: single rounded cylinder at outer edge
        translate([-(tube_outer_diameter / 2) - cradle_flare_amount + flare_top_r, straight_height + cradle_flare_height, 0])
            cylinder(r = flare_top_r, h = length);
    }
    
    // Right wall flare (flares outward in +X direction)
    hull() {
        // Bottom of flare: matches straight wall
        translate([(tube_inner_diameter / 2), straight_height, 0])
            cube([tube_wall_thickness, 0.01, length]);
        // Top of flare: single rounded cylinder at outer edge
        translate([(tube_outer_diameter / 2) + cradle_flare_amount - flare_top_r, straight_height + cradle_flare_height, 0])
            cylinder(r = flare_top_r, h = length);
    }
}

module curved_bearing_lip() {
    // Bearing lip with curved flare at the base
    // Curves at cradle connection, flat ring at bearing contact surface
    
    lip_r = bearing_lip_od / 2;         // Radius of the bearing contact surface
    max_flare_r = tube_outer_diameter / 2 - 0.5; // Maximum flare (just under pipe outer)
    
    // Define the 2D profile path
    profile_path = [
        [0, 0],  // Center at pipe connection
        [lip_r + bearing_lip_flare_amount, 0],  // Start with flared radius at pipe
        
        // Curved flare section - contracts inward as it extends out
        for (t = [0.1 : 0.1 : 0.9]) 
            let(
                z = t * bearing_lip_flare_length,
                // Concave curve inward - stays wider longer then contracts
                r = lip_r + bearing_lip_flare_amount * pow(1-t, 2)
            ) [r, z],
        
        [lip_r, bearing_lip_flare_length],  // End of flare at normal lip radius
        [lip_r, bearing_lip_flare_length + bearing_lip_extension],  // Straight section (flat ring for bearing)
        [0, bearing_lip_flare_length + bearing_lip_extension]  // Back to center at bearing contact
    ];
    
    // Create the 3D shape
    rotate_sweep(profile_path, angle=360);
}
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

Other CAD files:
STLs/filter_holder_interior-false_exterior-false.stl
leg_base/leg_base_2_legs.scad
leg_base/leg_base_4_legs.scad
filter_holder/filter_holder.scad
leg_base/testing/base_test.scad
leg_base/testing/curved_base.scad
leg_foot/leg_foot.scad
nozzle/nozzle/Naca_sweep.scad
nozzle/nozzle/Threading.scad
nozzle/nozzle/garden_hose_nozzle-5-prong-fan-out.scad
nozzle/testing/circular-nozzle/garden_hose_nozzle-5-prong-circular.scad
nozzle/testing/nozzle2/Naca_sweep.scad
nozzle/testing/nozzle2/Threading.scad
nozzle/testing/nozzle2/garden_hose_nozzle-5-prong-fan-out-2 - rev1.scad
nozzle/testing/nozzle2/garden_hose_nozzle-5-prong-fan-out-2 - rev2.scad
nozzle/testing/nozzle2/garden_hose_nozzle-5-prong-fan-out-2.scad

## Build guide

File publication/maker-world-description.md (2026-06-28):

# Horizontal Spinning Pool Filter Cleaning Stand

Cleaning a pool cartridge filter is slow going by hand. This stand holds the filter horizontally on a single rod and lets it spin freely on bearings, so you just point a hose nozzle at it and let the water do the work. The filter spins up fast, the spray drives down into the pleats, and the centrifugal force from the spinning helps fling debris out of the filter. A typical filter cleans up in a few minutes.

I designed and modeled every part myself in OpenSCAD, working from measurements I took of my own filters and equipment. It is sized for standard cylindrical cartridge filters (roughly 3 ft long by 9 in diameter, with about a 3 in center opening).

Every part is fully parametric, so it can be customized extensively. Filter diameter, plug size, rod diameter, bearing pocket, leg length and angle, drainage holes, and more are all driven by variables in the source. Full source files, all the print variants, and the build docs are on GitHub: https://github.com/billism1/pool-filter-cleaner

## How it works

The filter lies on its side, supported at both ends. A printed filter holder presses into each end of the cartridge, and a sealed ball bearing seats in each holder. A single aluminum rod runs straight through both holders and bearings, and the rod is held fixed by two leg bases on the ground. When you spray the filter it spins freely on the bearings while the rod stays still.

One leg base is a closed cradle and the other is an open-top cradle, so you can load the whole filter and rod assembly by laying it into the stand from above instead of threading it in end first. Everything is press fit. Set screw holes are built in if you ever want them, but most builds do not need them.

## What you print

This is the set I print and use:

- 2x filter holder (`filter_holder_interior-false_exterior-true.stl`), one pressed into each end of the filter
- 1x closed-end leg base (`leg_base_2_legs_both_sides-false.stl`)
- 1x open-top cradle leg base (`leg_base_2_legs_top_insert.stl`)
- 4x leg foot (`leg_foot.stl`), one capping each leg rod
- Optional: 1x garden hose nozzle (`garden_hose_nozzle-5-prong-fan-out.stl`)

A pre-arranged `pool-filter-cleaner.3mf` with all of these laid out across plates is included, so you can drop it straight into your slicer.

## What you supply (hardware)

- 2x S6904ZZ ball bearings (37 mm OD x 20 mm ID x 9 mm)
- 1x 3/4 in (19.05 mm) aluminum rod for the main filter axle, about 36 to 40 in long
- 4x 3/4 in (19.05 mm) aluminum rods for the legs, about 24 to 36 in each (set your working height)
- Optional: up to 6x M4 set screws
- A garden hose with a forceful nozzle. The included 5 jet nozzle is optional; any nozzle with a strong, focused stream works.

## Print settings

- Material: PETG or ABS for outdoor durability and chemical resistance
- Layer height: 0.2 mm
- Infill: 30 to 40 percent for the holders and bases
- Supports: not needed. Print the filter holders flange side down and the leg bases on their curved base.

## Optional spray nozzle

I include an optional garden hose compatible spray nozzle (3/4 in GHT) with five fanned out jets aimed at the filter. It is a nice extra, but any nozzle with a strong, focused stream works just as well.

Print the nozzle in ASA or ABS and acetone vapor smooth the inside and outside surfaces. Without smoothing, small droplets of water slowly seep right through the print lines in the material. The vapor smoothing closes those layer lines and stops the seepage.

## Assembly

1. Press a bearing into each filter holder.
2. Press a filter holder into each end of the cartridge.
3. Slide the aluminum rod through both holders and bearings.
4. Set the rod into the two leg bases, dropping one end into the open-top cradle.
5. Push a leg rod into each leg socket and cap each with a leg foot. Level it on the ground.
6. Connect your hose nozzle, turn on the water, and spray along the filter while it spins. Roughly 2 to 5 minutes per filter depending on how dirty it is.

## Notes

- Keep water pressure reasonable (do not exceed about 80 PSI) to protect the printed parts.
- This is an independent, personal, non commercial project. Source files are in OpenSCAD if you want to remix or resize.

## Credits

Designed and modeled by me in OpenSCAD from my own measurements. The optional nozzle uses the Threading and Naca_sweep OpenSCAD libraries by Rudolf Huttary (Berlin). The leg bases use the BOSL2 library.

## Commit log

2026-02-21 Update README.md for clarity on set screws and attribution
2026-02-22 rename file.
    [leg_base_2_legs.scad]
2026-02-22 Adding 4 leg version of leg holder.
    [leg_base_4_legs.scad]
2026-02-22 Fix horizontal_through_hole_both_sides for 2 leg holder.
    [leg_base_2_legs.scad]
2026-02-22 Fixing horizontal_through_hole_both_sides for 4 leg holder.
    [leg_base_4_legs.scad]
2026-02-22 Default to through-hoel for horizontal 2-leg holders.
    [leg_base_2_legs.scad]
2026-02-22 leg base STL generation
    [leg_base.stl, leg_base_2_legs-closed_end.stl, leg_base_2_legs-through_hole.stl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]
2026-02-22 Enable partial sweep for printing base to save material
    [leg_base_2_legs.scad]
2026-03-24 Update STL files and optimize SCAD parameters for improved rendering
    [leg_base_2_legs-closed_end.stl, leg_base_2_legs-through_hole.stl, leg_base_2_legs.scad]
2026-06-28 2026 06 27 updates (#2)
    * Refactor curved printing base logic and add top-insert cradle variant
    * consolidate bearing placement params to single scad file for filte rholder.
    * Enhance rendering scripts and update SCAD files for improved output quality
    - Increased the `$fn` parameter in `leg_base_2_legs.scad` and `leg_base_2_legs_top_insert.scad` to 180 for higher resolution renders.
    - Added a new PowerShell script `render_all.ps1` to automate the rendering of SCAD files to STL format, including support for multiple configurations.
    - Updated `leg_foot.stl` to reflect changes in the binary file.
    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
    [filter_holder.scad, filter_holder.stl, filter_holder_double_bearing.scad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]
2026-11-07 Adding double tube clip
2026-11-07 Add openscad-preview skill and preview_scad.ps1 script
    Skill drives a render -> view PNG -> edit loop for .scad files.
    Script renders PNG previews from fixed camera angles.
2026-11-07 Add Angled Tube Clip Coupler module for versatile tube connections
    - Introduced a new module for creating an angled tube clip coupler that allows two tubes to connect at any angle, with a default of 90°.
    - Implemented customizable tube presets and clearance options for various tube sizes.
    - Enhanced printability by designing the clips to lean at an angle, reducing the need for supports during 3D printing.
    - Added parameters for edge rounding and clip dimensions to improve aesthetics and functionality.
    - Included comprehensive echo statements to verify computed dimensions and parameters for user feedback.
